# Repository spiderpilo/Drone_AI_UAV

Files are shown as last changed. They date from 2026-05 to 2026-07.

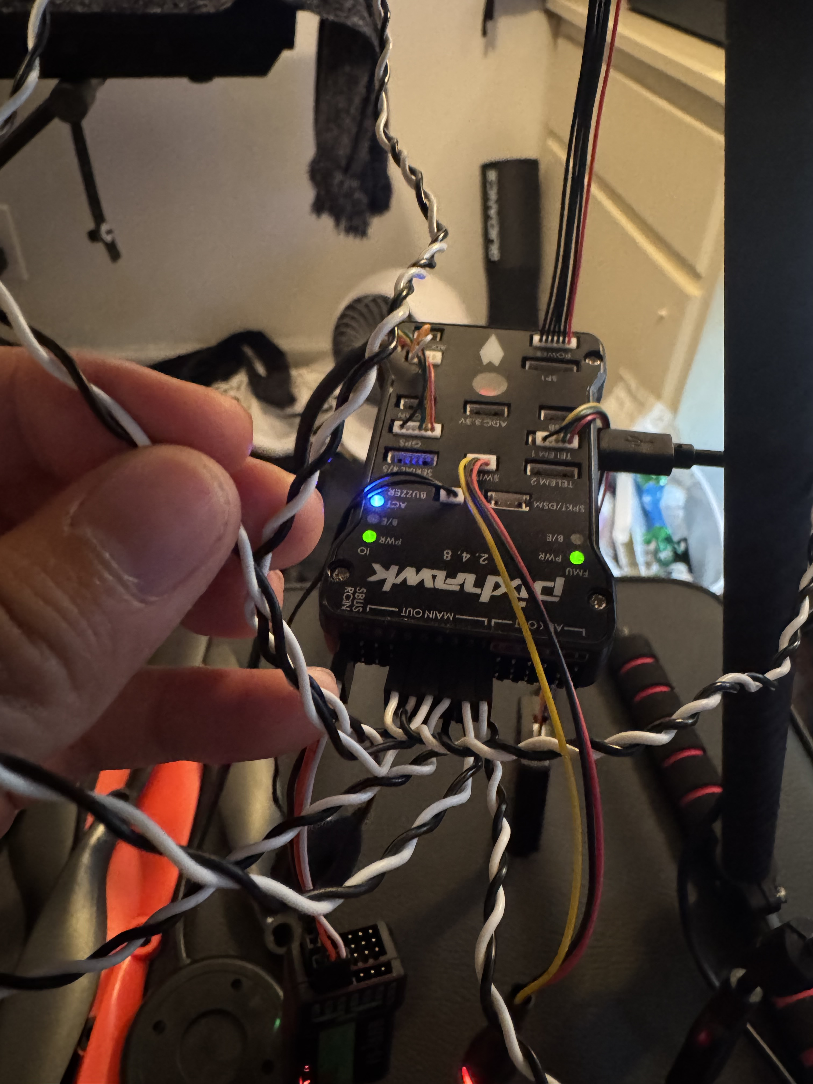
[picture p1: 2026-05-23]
media/photos/PixhawkCalibration.jpeg

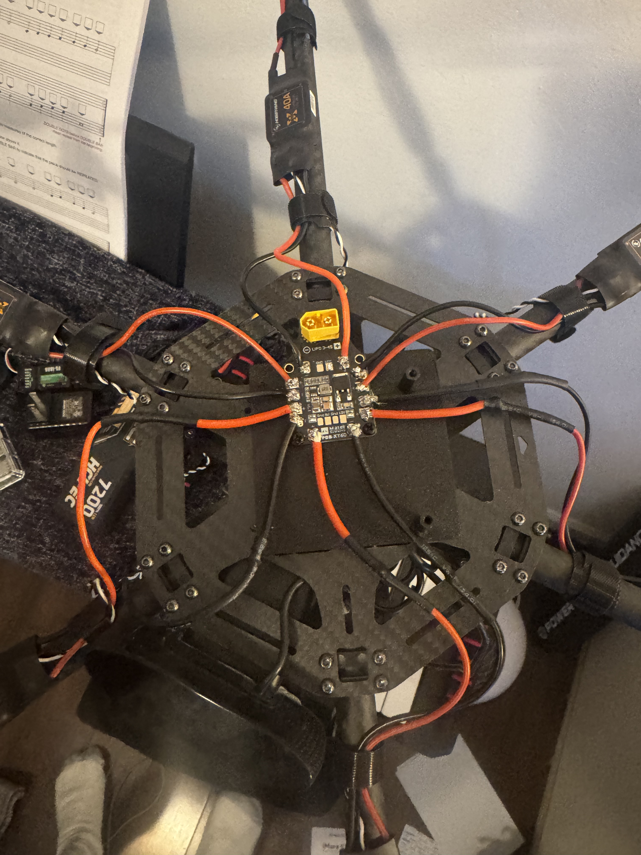
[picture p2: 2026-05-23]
media/photos/ESC's_to_PDB.jpeg

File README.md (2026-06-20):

# AI Vision Follow Drone

An autonomous drone system that uses computer vision to detect and follow a target while maintaining a safe, configurable distance.  
This project focuses on real-time perception, control feedback, and hardware–software integration for autonomous flight.

---

## 🚁 Project Overview

The goal of **AI Vision Follow Drone** is to design and build an autonomous drone capable of:

- Detecting a human target using computer vision
- Tracking the target in real time
- Maintaining a consistent following distance
- Adapting movement based on the target’s position and motion
- Operating safely with hardware constraints and fail-safes

This project is built as a **full-stack robotics system**, combining AI perception, control logic, embedded hardware, and mechanical design.

---

## Raspberry Pi SSH

The Pi runs as its own WiFi hotspot — no external router needed.

1. Power on the Pi and wait ~30 seconds for boot
2. Connect to WiFi: **DroneAI** / password: **Bullet1234**
3. SSH in: `ssh piolo@192.168.4.1`

### Running the detection script

```bash
# Dry run (camera + detection only, no flight commands)
python3 ~/drone/person_detection.py --dry-run

# With live video stream (open http://192.168.4.1:8080 in browser)
python3 ~/drone/person_detection.py --dry-run --stream

# Full run with Pixhawk connected
python3 ~/drone/person_detection.py --port /dev/ttyACM0 --stream
```

### Updating the software

After editing code locally in VSCode, push your changes and pull them on the Pi:

**On your computer (VSCode terminal):**
```bash
git add -A && git commit -m "your message" && git push
```

**On the Pi (SSH session):**
```bash
cd ~/drone
git pull
```

The updated code is now ready to run on the Pi.

---

## Custom Model Training

Fine-tune YOLOv8n on person detection data and deploy via Docker.

### 1. Train the model (on your Mac)

```bash
pip install -r training/requirements.txt
python3 training/train.py --epochs 30
```

The trained model is saved to `training/output/person_detector.onnx`.

### 2. Build and deploy with Docker

Copy the trained model into the Docker build context, then deploy to the Pi:

```bash
cp training/output/person_detector.onnx docker/models/
./docker/deploy.sh
```

### 3. Run on the Pi

```bash
# Dry run (camera only)
docker run --rm --device /dev/video0 drone-vision --dry-run

# With Pixhawk + live stream
docker run --rm --device /dev/video0 --device /dev/ttyACM0 -p 8080:8080 drone-vision --port /dev/ttyACM0
```

> **Note:** Docker must be installed on the Pi first:
> ```bash
> curl -fsSL https://get.docker.com | sh
> sudo usermod -aG docker piolo
> ```

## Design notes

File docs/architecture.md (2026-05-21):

# System Architecture

## Overview

This project is an AI-assisted UAV platform designed to combine autonomous flight control, edge computer vision, and modular hardware expansion.

The system uses a Pixhawk flight controller for low-level flight stabilization and safety-critical control, while a Raspberry Pi handles higher-level AI tasks such as person detection, target tracking, and future autonomous decision-making.

The goal is not to replace the flight controller, but to build an intelligent companion system around it.

---

## High-Level Architecture

text
USB Camera
    ↓
Raspberry Pi 4
    ↓
Computer Vision / AI Detection
    ↓
Tracking Logic
    ↓
MAVLink Communication
    ↓
Pixhawk Flight Controller
    ↓
ESCs
    ↓
Brushless Motors

# Core Components

## Raspberry Pi 4

The Raspberry Pi acts as the onboard companion computer.

### Responsibilities:

Run computer vision models
Process camera input
Detect and track people or objects
Send high-level movement commands to the Pixhawk
Handle future AI features such as fire detection or threat detection

The Pi does not directly control the motors. Instead, it communicates with the Pixhawk.

## Pixhawk Flight Controller

The Pixhawk handles the critical flight-control layer.

### Responsibilities:

Stabilization
Motor mixing
ESC control
GPS-based positioning
Flight modes
Failsafe behavior
RC control override

The Pixhawk remains responsible for safe flight behavior.

## USB Camera

The USB camera provides the visual input for the AI system.

### Responsibilities:

Capture live video frames
Provide input to the person/object detection model
Allow the Raspberry Pi to estimate target position in the frame
AI Vision Module

The AI vision module processes camera frames and detects objects.

# Initial goal:

Detect a person using a pretrained object detection model

# Future goals:

Fire detection
Threat detection
Multi-object tracking
Search and rescue support
Tracking Module

The tracking module converts AI detection results into movement intent.

Example:

Person is left of center → rotate or move left
Person is right of center → rotate or move right
Person is too small → move forward
Person is too large → move backward or hold position

This module produces high-level movement commands, not direct motor commands.

## MAVLink Communication Layer

MAVLink is used for communication between the Raspberry Pi and Pixhawk.

### Responsibilities:

Send guided movement commands
Read telemetry data
Monitor drone state
Check arming status
Detect failsafe conditions

Example data exchanged:

Drone altitude
GPS position
Battery status
Flight mode
Target movement commands
Data Flow
1. Camera captures video frame
2. Raspberry Pi reads frame
3. AI model detects target
4. Tracking module calculates target offset
5. Raspberry Pi sends movement command through MAVLink
6. Pixhawk executes safe flight adjustment
7. Pixhawk continues stabilization and failsafe monitoring
Safety Design

The system is designed with the Pixhawk as the primary safety controller.

# Safety principles:

Manual RC control has priority
Pixhawk handles stabilization
Pixhawk handles failsafes
Raspberry Pi only sends high-level commands
Autonomous behavior can be disabled
Low battery should trigger landing or RTL
Loss of communication should stop autonomous movement
Flight Control Philosophy

This project separates flight control into two layers:

### Low-Level Control

Handled by Pixhawk.

Includes:

Motor control
Stabilization
ESC output
Attitude control
GPS hold
Return-to-launch behavior
High-Level Autonomy

### Handled by Raspberry Pi.

Includes:

Person detection
Tracking decisions
AI-based perception
Future mission logic

This separation makes the system safer and easier to debug.

Current Development Stage

# Current focus:

Build and document the UAV hardware platform
Set up Pixhawk-based flight control
Connect Raspberry Pi as a companion computer
Run person detection using a USB camera
Test tracking logic without full autonomous flight first
Planned Architecture Improvements

# Future upgrades may include:

Jetson or Coral TPU for faster AI inference
Thermal camera for fire detection
Custom PCB for power distribution and sensor integration
ROS2 integration
Obstacle avoidance sensors
Better telemetry dashboard
Autonomous mission planning
Onboard logging system
Design Reasoning

This architecture was chosen because it allows the project to grow safely.

Instead of trying to build a flight controller from scratch, the Pixhawk handles proven flight-control responsibilities. This lets the Raspberry Pi focus on AI, perception, and higher-level decision-making.

This makes the project more realistic, modular, and closer to how real robotics systems are designed.

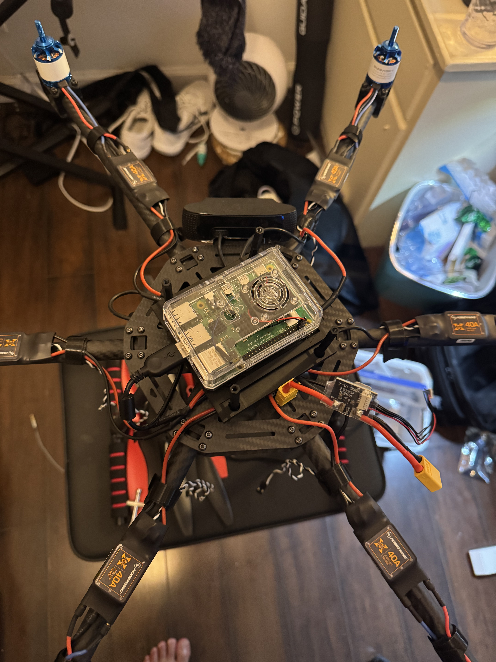
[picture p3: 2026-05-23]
media/photos/RasberryPi_mounted.jpeg

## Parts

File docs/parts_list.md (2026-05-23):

### Drone Frame
- X600 600mm Carbon Fiber Hexacopter Drone Frame Kit

### Flight Controller
- Pixhawk PX4 PIX 2.4.8

### Reciever & Transmitter
- FLYSKY FS-i6X 10CH 2.4GHz RC Transmitter Controller with FS-iA6B Receiver

### Battery
- SMC SMC72100-4S1PXT90 HCL-EC 14.8V 7200mAh Lipo Battery 100C w/XT90

### ESC (Electronic Speed Controller)
- Hobbywing Xrotor-40A Multirotor ESC

### Motors
- SunnySky X Series V3 X2216 V3 Brushless Motors

### PDB (Power Distribution Board)
- Acxico Board XT60 3-4S 9-18V 5V 12V Output PDB

### Computer 
- Raspberry Pi 4

### Webcam
- Logitech C920s HD Pro Webcam

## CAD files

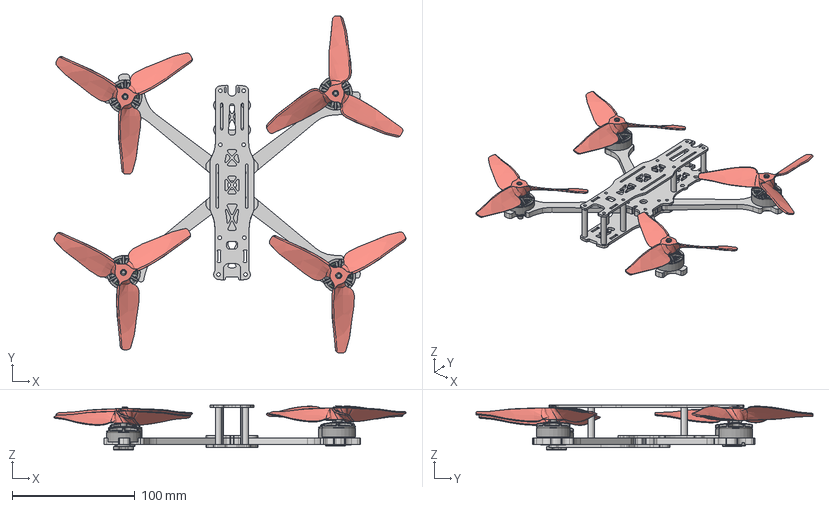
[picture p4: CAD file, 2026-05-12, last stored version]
CAD/Assembly/Drone_Assembly.step
286.6 x 274.6 x 36.6 mm
2207 motor_1_1 x 4
Propeller_V4 CW x 4

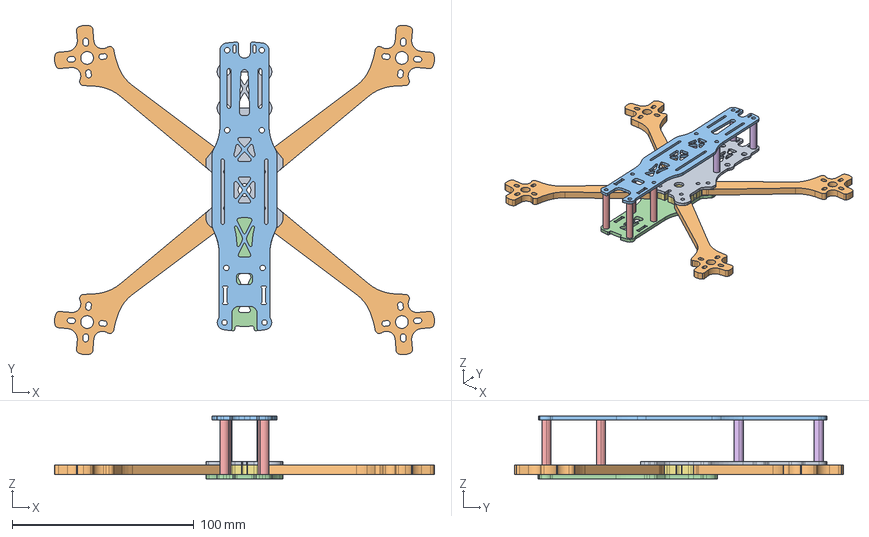
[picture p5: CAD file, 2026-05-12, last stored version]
CAD/Vendor_parts/Frame/files/tbs_sourceone_v5_asm.stp
209.0 x 181.2 x 34.5 mm
PRT0001
SOURCEONE_BOTTOMPLATE
SOURCEONE_ARMS
SOURCEONE_TOPPLATE
SOURCEONE_BOTTOMPLATE2
SOURCEONE_SPACER
SOURCEONE_ARM_STIFFER

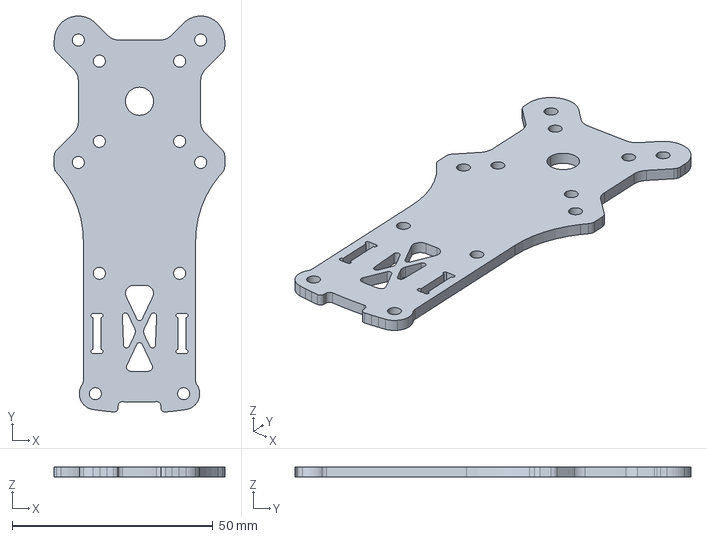
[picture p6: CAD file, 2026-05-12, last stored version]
CAD/Vendor_parts/Frame/files/sourceone_bottomplate2_1.stp
42.5 x 98.7 x 2.50 mm

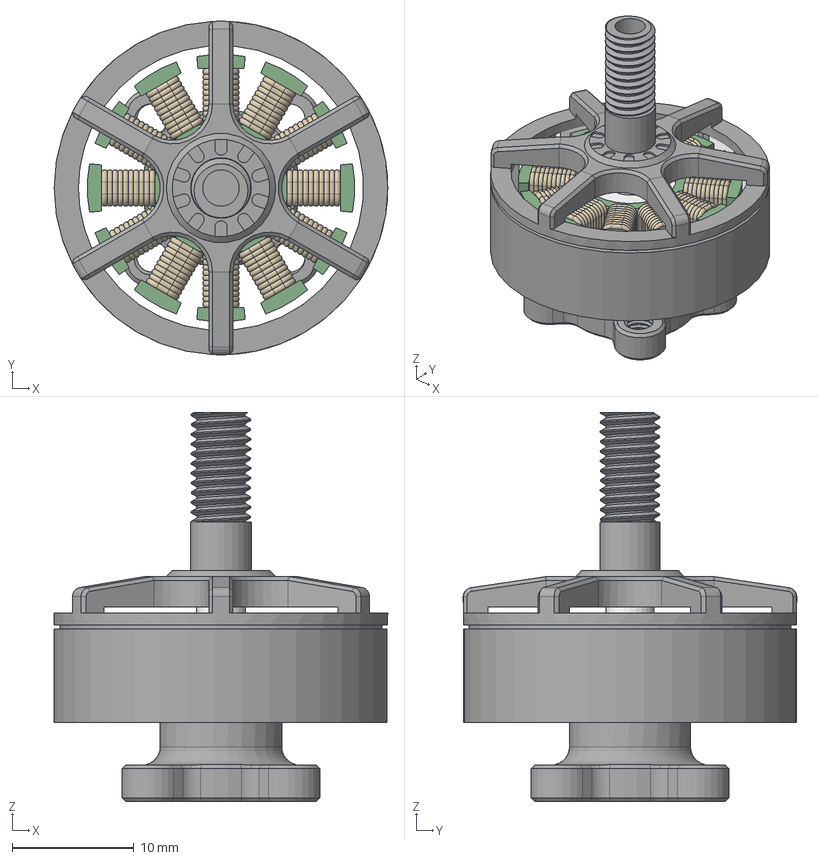
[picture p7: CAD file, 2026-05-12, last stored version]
CAD/Vendor_parts/Motors/2207 motor.step
27.4 x 27.4 x 32.0 mm

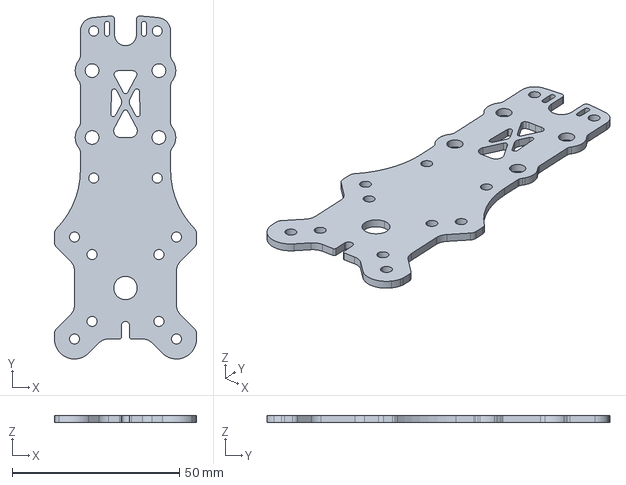
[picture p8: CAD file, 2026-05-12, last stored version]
CAD/Vendor_parts/Frame/files/sourceone_bottomplate_1.stp
42.5 x 102.6 x 2.00 mm

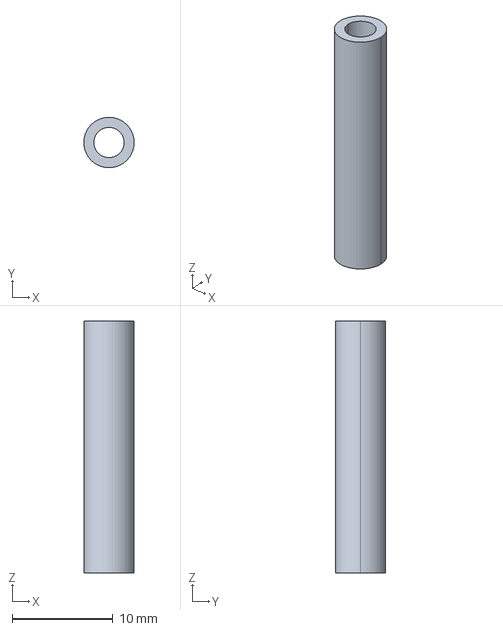
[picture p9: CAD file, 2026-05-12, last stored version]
CAD/Vendor_parts/Frame/files/sourceone_spacer_short.stp
5.00 x 5.00 x 25.0 mm

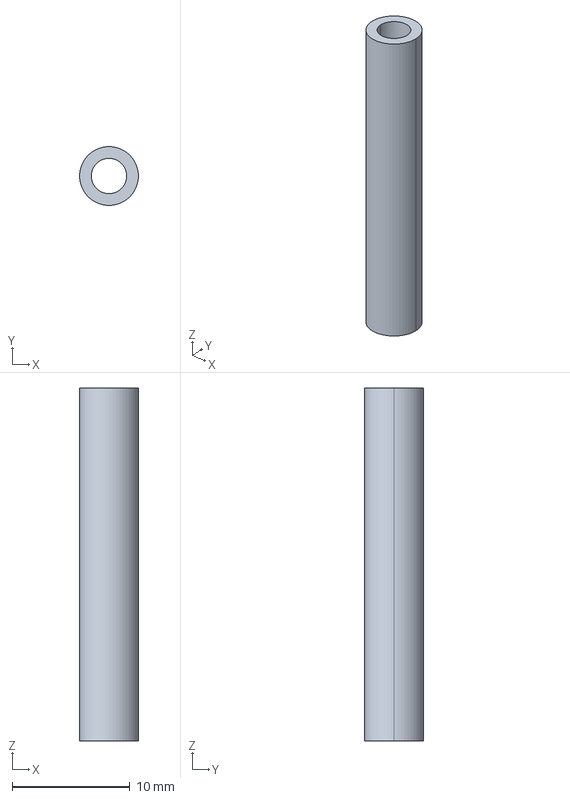
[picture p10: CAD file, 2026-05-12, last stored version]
CAD/Vendor_parts/Frame/files/sourceone_spacer_long.stp
5.00 x 5.00 x 30.0 mm

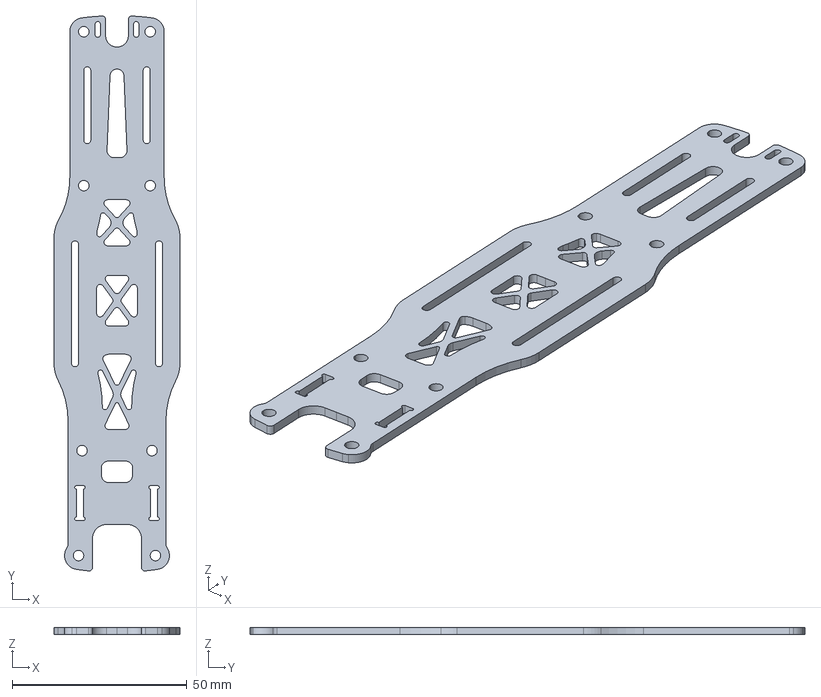
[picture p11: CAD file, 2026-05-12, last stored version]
CAD/Vendor_parts/Frame/files/sourceone_topplate_1.stp
36.0 x 158.7 x 2.00 mm

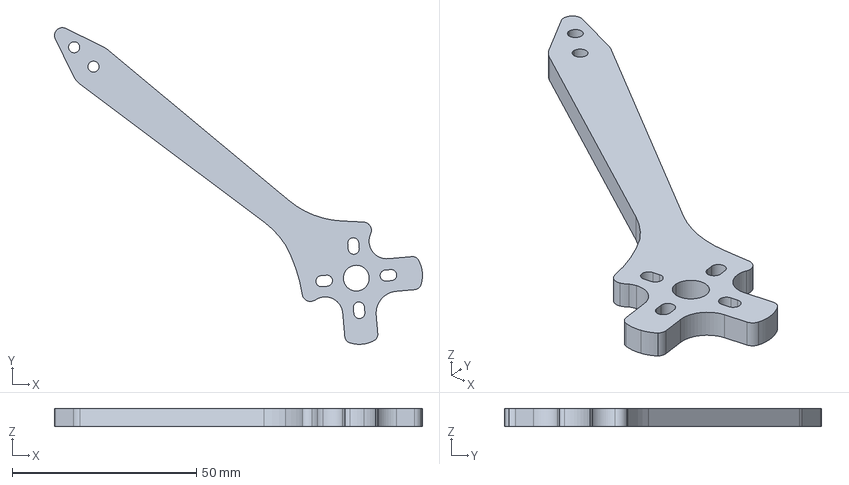
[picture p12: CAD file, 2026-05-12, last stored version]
CAD/Vendor_parts/Frame/files/sourceone_arms_1_3.stp
99.8 x 85.9 x 5.00 mm

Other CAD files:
CAD/Vendor_parts/Frame/files/tbs_sourceone_v5.stl

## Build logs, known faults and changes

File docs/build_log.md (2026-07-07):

# Build Log

### May 12, 2026
- Assembled Drone Frame. 
- Attached Motors and ESC's

### May 20, 2026 
- Set up Raspberry Pi with Linux Ubuntu
- Set up SSH for Raspberry Pi

### May 21, 2026
- Installed OpenCV (4.10.0), onnxruntime (1.26.0), pymavlink (2.4.49) on Pi
- Downloaded YOLOv8n ONNX model (~13 MB) to ~/drone/models/yolov8n.onnx
- Created person_detection.py: YOLOv8n person detection + MAVLink velocity commands to Pixhawk
- Configured Pi as WiFi access point (SSID: DroneAI, IP: 192.168.4.1)
  - Auto-starts on boot via NetworkManager — no router needed in the field
  - Connect: WiFi → DroneAI / Bullet1234, then ssh piolo@192.168.4.1

### May 22, 2026
- Soldered ESC's (electronic speed controllers) to PDB (power distribution board)
- 3D printed custom mounts
- Mounted Webcam

### May 23, 2026
- Mounted Raspberry Pi 4 onto frame
- Motor Tests: ALL PASS
- Reciever and transmitter pairing and testing

### May 29, 2026
- Calibrated Pixhawk 
- Removed Webcam and Raspberry Pi for flight testing

### June 8, 2026
- Drone ARMED successfully via channel 2
- First Test Flight: Drone tilts on one side before take off

### June 9, 2026
- Recalibrated Drone on QC ground control
- Fixed motor Orientation 
- Test Flight 2: Drone lifted from ground Succesfully 

### June 10, 2026
- Test flight 3: Drone succesfully leaves ground 
- Drone appears to be difficult to control and hard to maintain a fixed height

### July 7, 2026
- Re-Alligned motors and propllers
- Added Loiter function to the Controller.(Maintain Drone postion)

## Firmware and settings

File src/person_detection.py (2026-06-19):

#!/usr/bin/env python3
"""
Person detection and drone following via MAVLink.

Pipeline:
  USB camera -> YOLOv8n (ONNX/onnxruntime) -> person bbox
  -> proportional velocity controller -> MAVLink -> Pixhawk (GUIDED mode)

Hardware:
  - Raspberry Pi (aarch64, Ubuntu 26.04)
  - Pixhawk PX4 2.4.8 connected via USB (/dev/ttyACM0) or UART (/dev/ttyAMA0)
  - USB camera

Usage:
  python3 person_detection.py
  python3 person_detection.py --port /dev/ttyAMA0 --baud 57600 --camera 0
  python3 person_detection.py --dry-run   # camera + detection only, no flight commands
  python3 person_detection.py --stream    # live video at http://192.168.4.1:8080
"""

import argparse
import os
import sys
import threading
import time
from http.server import HTTPServer, BaseHTTPRequestHandler

import cv2
import numpy as np
import onnxruntime as ort
from pymavlink import mavutil

# ---------------------------------------------------------------------------
# Configuration (override via CLI args or environment variables)
# ---------------------------------------------------------------------------
DEFAULT_MODEL   = os.path.expanduser("~/drone/models/yolov8n.onnx")
DEFAULT_PORT    = os.environ.get("PIXHAWK_PORT", "/dev/ttyACM0")
DEFAULT_BAUD    = int(os.environ.get("PIXHAWK_BAUD", "57600"))
DEFAULT_CAMERA  = int(os.environ.get("DRONE_CAMERA", "0"))

# Detection
CONF_THRESHOLD  = 0.50   # minimum confidence to accept a detection
NMS_THRESHOLD   = 0.45   # NMS IoU threshold
PERSON_CLASS    = 0      # COCO class 0 = person
INPUT_SIZE      = 640    # YOLOv8 expects 640x640

# Control tuning  (adjust these during flight tests)
KP_YAW          = 0.6    # yaw rate gain  (rad/s per normalised pixel error)
KP_ALTITUDE     = 0.4    # vertical velocity gain (m/s per normalised error)
KP_DISTANCE     = 0.5    # forward/backward gain  (m/s per normalised error)
TARGET_SIZE     = 0.35   # desired person height as fraction of frame height
MAX_SPEED_H     = 0.8    # m/s horizontal clamp
MAX_SPEED_V     = 0.4    # m/s vertical clamp
CMD_RATE_HZ     = 10     # how often to send MAVLink velocity commands
PERSON_LOST_S   = 1.0    # seconds before issuing hover when person disappears

# MAVLink type_mask: use velocity (vx, vy, vz) + yaw_rate only
# Bit=1 means IGNORE that field.  bits[10..0]: yaw_rate, yaw, az, ay, ax, vz, vy, vx, pz, py, px
# Use vx(bit3), vy(bit4), vz(bit5), yaw_rate(bit10)  ->  ignore rest
_TYPE_MASK_VEL_YAW = (
    (1 << 0) | (1 << 1) | (1 << 2) |           # ignore position
    (1 << 6) | (1 << 7) | (1 << 8) |           # ignore acceleration
    (1 << 9)                                     # ignore yaw (use yaw_rate)
)  # = 967


# ---------------------------------------------------------------------------
# Person detector using YOLOv8n ONNX
# ---------------------------------------------------------------------------
class PersonDetector:
    def __init__(self, model_path: str):
        if not os.path.exists(model_path):
            sys.exit(f"[detector] Model not found: {model_path}\n"
                     f"  Run: python3 -c \"import urllib.request; "
                     f"urllib.request.urlretrieve('https://github.com/ultralytics/assets/"
                     f"releases/download/v8.4.0/yolov8n.onnx', '{model_path}')\"")

        self._sess = ort.InferenceSession(
            model_path,
            providers=["CPUExecutionProvider"]
        )
        self._in_name  = self._sess.get_inputs()[0].name
        self._out_name = self._sess.get_outputs()[0].name
        print(f"[detector] Loaded {model_path}")

    def detect(self, frame: np.ndarray) -> list[dict]:
        """
        Returns list of { 'bbox': (x, y, w, h), 'conf': float } for every person
        detected above CONF_THRESHOLD in the given BGR frame.
        """
        h, w = frame.shape[:2]
        img, scale, pad_x, pad_y = self._preprocess(frame, w, h)

        raw = self._sess.run([self._out_name], {self._in_name: img})[0]
        # YOLOv8 ONNX output shape: (1, 84, 8400)
        # 84 = cx, cy, bw, bh + 80 class scores
        preds = raw[0].T  # -> (8400, 84)

        boxes, scores = [], []
        for pred in preds:
            cls_scores = pred[4:]
            cls_id = int(np.argmax(cls_scores))
            conf   = float(cls_scores[cls_id])
            if cls_id != PERSON_CLASS or conf < CONF_THRESHOLD:
                continue
            cx, cy, bw, bh = pred[:4]
            x1 = (cx - bw / 2 - pad_x) / scale
            y1 = (cy - bh / 2 - pad_y) / scale
            boxes.append([float(x1), float(y1), float(bw / scale), float(bh / scale)])
            scores.append(conf)

        if not boxes:
            return []

        indices = cv2.dnn.NMSBoxes(boxes, scores, CONF_THRESHOLD, NMS_THRESHOLD)
        results = []
        for i in (indices.flatten() if hasattr(indices, "flatten") else indices):
            x, y, bw, bh = boxes[i]
            results.append({
                "bbox": (int(x), int(y), int(bw), int(bh)),
                "conf": scores[i],
            })
        return results

    @staticmethod
    def _preprocess(frame, w, h):
        scale  = INPUT_SIZE / max(w, h)
        nw, nh = int(w * scale), int(h * scale)
        resized = cv2.resize(frame, (nw, nh))
        canvas  = np.full((INPUT_SIZE, INPUT_SIZE, 3), 114, dtype=np.uint8)
        pad_x   = (INPUT_SIZE - nw) // 2
        pad_y   = (INPUT_SIZE - nh) // 2
        canvas[pad_y:pad_y + nh, pad_x:pad_x + nw] = resized
        blob = canvas.astype(np.float32) / 255.0
        blob = blob.transpose(2, 0, 1)[np.newaxis]   # HWC -> 1CHW
        return blob, scale, pad_x, pad_y


# ---------------------------------------------------------------------------
# MAVLink drone interface
# ---------------------------------------------------------------------------
class DroneController:
    def __init__(self, port: str, baud: int):
        print(f"[mavlink] Connecting to {port} @ {baud} baud …")
        self.master = mavutil.mavlink_connection(port, baud=baud)
        hb = self.master.wait_heartbeat(timeout=10)
        if hb is None:
            raise TimeoutError(f"No heartbeat from Pixhawk on {port}")
        self.sys  = self.master.target_system
        self.comp = self.master.target_component
        print(f"[mavlink] Heartbeat: system={self.sys} component={self.comp}")

    def set_guided_mode(self):
        """Request GUIDED mode (ArduCopter). For PX4 firmware use OFFBOARD instead."""
        self.master.mav.command_long_send(
            self.sys, self.comp,
            mavutil.mavlink.MAV_CMD_DO_SET_MODE,
            0,
            mavutil.mavlink.MAV_MODE_FLAG_CUSTOM_MODE_ENABLED,
            4,   # ArduCopter GUIDED = 4
            0, 0, 0, 0, 0,
        )
        print("[mavlink] Requested GUIDED mode")

    def send_velocity(self, vx: float, vy: float, vz: float, yaw_rate: float = 0.0):
        """
        Send body-frame velocity command.
        vx = forward (+) / backward (-)  m/s
        vy = right (+) / left (-)         m/s
        vz = down (+) / up (-)            m/s  (NED convention)
        yaw_rate = clockwise (+) rad/s
        """
        self.master.mav.set_position_target_local_ned_send(
            int(time.monotonic() * 1000) & 0xFFFF_FFFF,
            self.sys, self.comp,
            mavutil.mavlink.MAV_FRAME_BODY_OFFSET_NED,
            _TYPE_MASK_VEL_YAW,
            0, 0, 0,              # position (ignored)
            vx, vy, vz,           # velocity m/s
            0, 0, 0,              # acceleration (ignored)
            0, yaw_rate,          # yaw (ignored), yaw_rate rad/s
        )

    def stop(self):
        self.send_velocity(0.0, 0.0, 0.0, 0.0)


# ---------------------------------------------------------------------------
# Proportional controller
# ---------------------------------------------------------------------------
def compute_velocity(det: dict, frame_w: int, frame_h: int) -> tuple[float, float, float, float]:
    """
    Given a person detection and frame dimensions, return (vx, vy, vz, yaw_rate).

    Strategy:
      - yaw_rate: rotate drone so person stays horizontally centred
      - vz:       adjust altitude so person stays vertically centred
      - vx:       approach or retreat to maintain TARGET_SIZE bounding-box ratio
      - vy:       zero (yaw handles lateral tracking; strafe reserved for fine tuning)
    """
    x, y, bw, bh = det["bbox"]
    cx_norm = (x + bw / 2) / frame_w - 0.5    # -0.5 (left) .. +0.5 (right)
    cy_norm = (y + bh / 2) / frame_h - 0.5    # -0.5 (top)  .. +0.5 (bottom)
    size_err = (bh / frame_h) - TARGET_SIZE    # positive = too close

    yaw_rate = KP_YAW      * cx_norm
    vz       = KP_ALTITUDE * cy_norm           # positive cy_norm -> person below -> descend
    vx       = KP_DISTANCE * size_err          # positive -> too close -> move backward... wait
    # size_err > 0 means person is LARGER than target (too close) -> retreat (vx negative)
    vx       = -KP_DISTANCE * size_err
    vy       = 0.0

    vx  = float(np.clip(vx,       -MAX_SPEED_H, MAX_SPEED_H))
    vy  = float(np.clip(vy,       -MAX_SPEED_H, MAX_SPEED_H))
    vz  = float(np.clip(vz,       -MAX_SPEED_V, MAX_SPEED_V))
    yaw_rate = float(np.clip(yaw_rate, -1.5, 1.5))

    return vx, vy, vz, yaw_rate


# ---------------------------------------------------------------------------
# MJPEG streaming server (--stream flag)
# ---------------------------------------------------------------------------
STREAM_PORT = 8080

class _StreamServer:
    """Serves the latest annotated frame as an MJPEG stream over HTTP."""

    def __init__(self, port: int = STREAM_PORT):
        self._frame = None
        self._lock = threading.Lock()
        self._port = port

        parent = self

        class Handler(BaseHTTPRequestHandler):
            def do_GET(self):
                self.send_response(200)
                self.send_header("Content-Type",
                                 "multipart/x-mixed-replace; boundary=frame")
                self.end_headers()
                while True:
                    with parent._lock:
                        jpg = parent._frame
                    if jpg is None:
                        time.sleep(0.05)
                        continue
                    try:
                        self.wfile.write(b"--frame\r\n")
                        self.wfile.write(b"Content-Type: image/jpeg\r\n\r\n")
                        self.wfile.write(jpg)
                        self.wfile.write(b"\r\n")
                    except BrokenPipeError:
                        break
                    time.sleep(0.05)

            def log_message(self, *_):
                pass

        self._httpd = HTTPServer(("0.0.0.0", self._port), Handler)
        t = threading.Thread(target=self._httpd.serve_forever, daemon=True)
        t.start()
        print(f"[stream] Live video at http://192.168.4.1:{self._port}")

    def update(self, frame: np.ndarray):
        _, jpg = cv2.imencode(".jpg", frame, [cv2.IMWRITE_JPEG_QUALITY, 70])
        with self._lock:
            self._frame = jpg.tobytes()


def _annotate_frame(frame, detections, best, vx, vz, yr):
    """Draw bounding boxes and control info on the frame."""
    fh, fw = frame.shape[:2]

    # Crosshair at frame centre
    cv2.line(frame, (fw // 2 - 20, fh // 2), (fw // 2 + 20, fh // 2), (0, 255, 0), 1)
    cv2.line(frame, (fw // 2, fh // 2 - 20), (fw // 2, fh // 2 + 20), (0, 255, 0), 1)

    for det in detections:
        x, y, bw, bh = det["bbox"]
        color = (0, 255, 0) if det is best else (200, 200, 200)
        cv2.rectangle(frame, (x, y), (x + bw, y + bh), color, 2)
        cv2.putText(frame, f"{det['conf']:.0%}", (x, y - 6),
                    cv2.FONT_HERSHEY_SIMPLEX, 0.5, color, 1)

    if best:
        cv2.putText(frame, f"vx={vx:+.2f} vz={vz:+.2f} yr={yr:+.2f}",
                    (10, fh - 10), cv2.FONT_HERSHEY_SIMPLEX, 0.5, (0, 255, 0), 1)
    else:
        cv2.putText(frame, "NO PERSON", (10, fh - 10),
                    cv2.FONT_HERSHEY_SIMPLEX, 0.6, (0, 0, 255), 2)

    return frame


# ---------------------------------------------------------------------------
# Main loop
# ---------------------------------------------------------------------------
def run(args):
    detector = PersonDetector(args.model)

    drone = None
    if not args.dry_run:
        try:
            drone = DroneController(args.port, args.baud)
            drone.set_guided_mode()
        except Exception as exc:
            print(f"[mavlink] WARNING: {exc}")
            print("[mavlink] Continuing in camera-only mode (no flight commands)")

    stream = _StreamServer() if args.stream else None

    cap = cv2.VideoCapture(args.camera)
    if not cap.isOpened():
        sys.exit(f"[camera] Cannot open camera index {args.camera}")

    cap.set(cv2.CAP_PROP_FRAME_WIDTH,  640)
    cap.set(cv2.CAP_PROP_FRAME_HEIGHT, 480)
    fw = int(cap.get(cv2.CAP_PROP_FRAME_WIDTH))
    fh = int(cap.get(cv2.CAP_PROP_FRAME_HEIGHT))
    print(f"[camera] Opened at {fw}x{fh}")

    cmd_interval   = 1.0 / CMD_RATE_HZ
    last_cmd_t     = 0.0
    last_person_t  = 0.0
    hovering       = True

    print("[main] Running — press Ctrl+C to stop")
    try:
        while True:
            ret, frame = cap.read()
            if not ret:
                print("[camera] Frame read failed, retrying…")
                time.sleep(0.05)
                continue

            detections = detector.detect(frame)
            now = time.monotonic()

            best = None
            vx = vy = vz = yr = 0.0

            if detections:
                last_person_t = now
                hovering = False

                if now - last_cmd_t >= cmd_interval:
                    best = max(detections, key=lambda d: d["bbox"][2] * d["bbox"][3])
                    vx, vy, vz, yr = compute_velocity(best, fw, fh)

                    x, y, bw, bh = best["bbox"]
                    print(
                        f"[detect] person ({x+bw//2:3d},{y+bh//2:3d}) "
                        f"conf={best['conf']:.2f} "
                        f"vx={vx:+.2f} vz={vz:+.2f} yr={yr:+.2f}"
                    )

                    if drone:
                        drone.send_velocity(vx, vy, vz, yr)
                    last_cmd_t = now

            else:
                if not hovering and (now - last_person_t) > PERSON_LOST_S:
                    print("[detect] Person lost — hovering")
                    if drone:
                        drone.stop()
                    hovering = True

            if stream:
                annotated = _annotate_frame(frame.copy(), detections, best, vx, vz, yr)
                stream.update(annotated)

    except KeyboardInterrupt:
        print("\n[main] Interrupted")
    finally:
        if drone:
            drone.stop()
            print("[mavlink] Stop command sent")
        cap.release()
        print("[main] Done")


# ---------------------------------------------------------------------------
def main():
    parser = argparse.ArgumentParser(description="Drone person-following via MAVLink")
    parser.add_argument("--model",   default=DEFAULT_MODEL,  help="Path to yolov8n.onnx")
    parser.add_argument("--port",    default=DEFAULT_PORT,   help="Pixhawk serial port")
    parser.add_argument("--baud",    default=DEFAULT_BAUD,   type=int)
    parser.add_argument("--camera",  default=DEFAULT_CAMERA, type=int, help="Camera index")
    parser.add_argument("--dry-run", action="store_true",
                        help="Run detection only, send no flight commands")
    parser.add_argument("--stream",  action="store_true",
                        help="Serve live MJPEG video at http://192.168.4.1:8080")
    run(parser.parse_args())


if __name__ == "__main__":
    main()

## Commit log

2026-05-12 changed project architecture
    [2207 motor.step, Drone_Assembly.step, sourceone_arms_1_3.stp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]
2026-05-21 Docs update: Raspberry pi Ubuntu setup
2026-05-21 Docs update: setup raspberry pi ssh
2026-05-21 Docs: log Pi WiFi AP setup (DroneAI hotspot)
    Pi now boots as its own access point — no external router needed for
    field testing. Connect to DroneAI / ssh piolo@192.168.4.1.
2026-05-23 docs update: Soldered ESC's to PDB
2026-06-19 Add --stream flag for live MJPEG video feed
    Serves annotated camera frames (bounding boxes, control values) at
    http://192.168.4.1:8080 over the DroneAI WiFi. Uses Python built-in
    HTTP server — no extra dependencies needed.
